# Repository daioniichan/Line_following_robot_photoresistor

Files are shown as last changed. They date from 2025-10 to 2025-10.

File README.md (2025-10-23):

# Line Following Robot - Algorithm Documentation

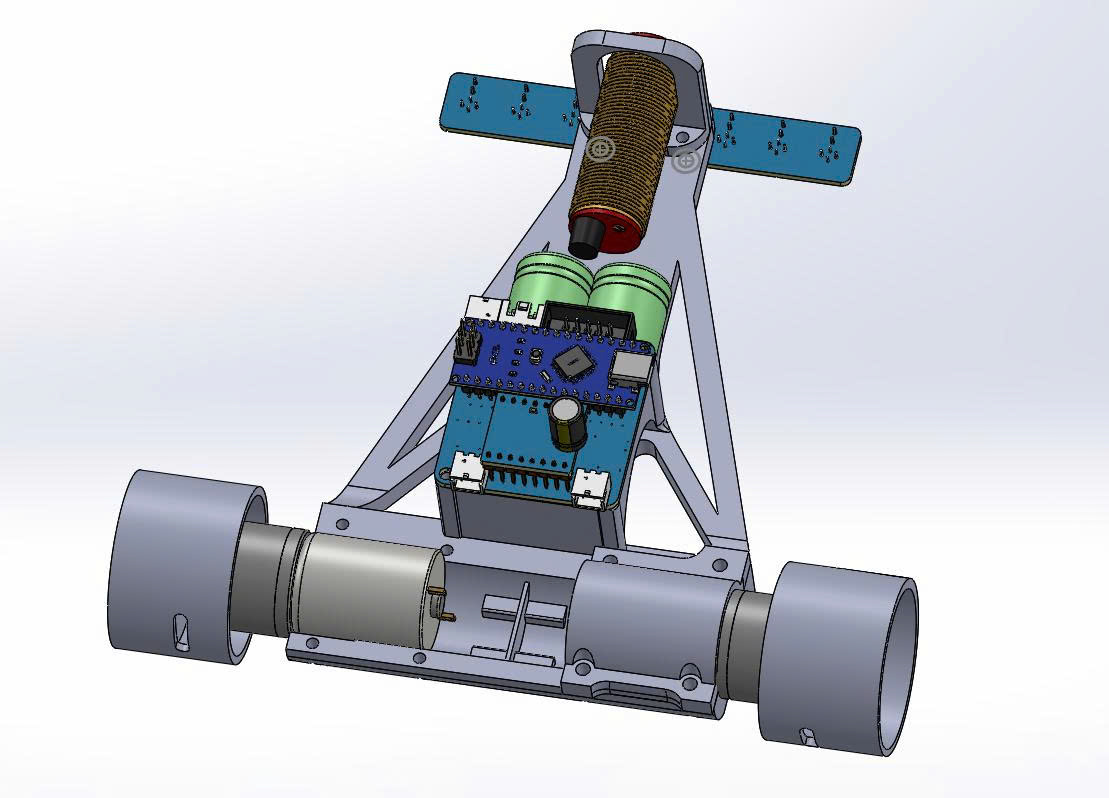
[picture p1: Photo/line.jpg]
anh1


## 📋 Tổng quan

Robot dò line sử dụng 8 cảm biến hồng ngoại với thuật toán PID để di chuyển theo đường line đen. Ngoài ra, robot còn có khả năng tránh vật cản sử dụng cảm biến NPN.

## 🔧 Cấu hình phần cứng

### Chân kết nối:
- **Cảm biến line**: A0-A7 (8 cảm biến analog)
- **Cảm biến vật cản**: Pin 2 (NPN_SENSOR_PIN)
- **Động cơ trái**: 
  - AIN1 (Pin 8), AIN2 (Pin 7)
  - PWMA (Pin 6)
- **Động cơ phải**:
  - BIN1 (Pin 4), BIN2 (Pin 3)
  - PWMB (Pin 5)
- **Nút điều khiển**:
  - SW1 (Pin 12), SW2 (Pin 9)
  - DIPSTW1 (Pin 10), DIPSTW2 (Pin 11)
- **Buzzer**: Pin 13

### Ánh xạ cảm biến:
```
sensorValue[7] ← A0 (trái ngoài cùng)
sensorValue[6] ← A2
sensorValue[5] ← A1
sensorValue[4] ← A4
sensorValue[3] ← A3
sensorValue[2] ← A6
sensorValue[1] ← A5
sensorValue[0] ← A7 (phải ngoài cùng)
```

## ⏱️ Timer Interrupt

### Cấu hình Timer 2:
- **Prescaler**: 1024
- **TCNT2**: 0xB2 (178)
- **Overflow**: 256 - 178 = 78 counts
- **Tần số ngắt**: (78 × 1024) / 16MHz ≈ **5ms**
- **Tần số đọc cảm biến**: **200 Hz**

Trong mỗi lần ngắt:
- Đọc giá trị 8 cảm biến
- Tính toán PID
- Tăng biến đếm `cnt`

## 🧮 Thuật toán PID

### 1. Calibration (Tự động chuẩn hóa)

Khi `isCalib = 1`, hệ thống tự động:
```cpp
if (black_value[i] == 0) black_value[i] = 1100;  // Khởi tạo
if (sensorValue[i] < black_value[i]) black_value[i] = sensorValue[i];  // Tìm min
if (sensorValue[i] > white_value[i]) white_value[i] = sensorValue[i];  // Tìm max
compare_value[i] = (black_value[i] + white_value[i]) / 2;  // Ngưỡng
```

### 2. Chuẩn hóa giá trị cảm biến

```cpp
sensorPID[j] = map(sensorValue[j], black_value[j], white_value[j], 0, 1000);
```
- Giá trị đen (line) → 0
- Giá trị trắng (nền) → 1000

### 3. Tạo byte sensor (binary representation)

```cpp
sensor = 0bXXXXXXXX  // 8 bit, mỗi bit đại diện cho 1 cảm biến
// Bit = 1 nếu cảm biến > compare_value (phát hiện trắng)
// Bit = 0 nếu cảm biến < compare_value (phát hiện đen/line)
```

**Ví dụ**:
- `0b00011000` = Line ở giữa (sensor 3, 4)
- `0b00000001` = Line ở phải ngoài cùng
- `0b10000000` = Line ở trái ngoài cùng
- `0b00011111` = Ngã tư (5 sensor phải phát hiện line)

### 4. Tính vị trí line (Weighted Average)

```cpp
avg = Σ(sensorPID[j] × j × 1000)  // j = 0..7
sum = Σ(sensorPID[j])
position = (avg / sum) - 3500
```

**Giải thích**:
- Vị trí trung tâm lý tưởng: (0+1+2+3+4+5+6+7)/8 × 1000 = 3500
- `position < 0`: Line lệch về phải
- `position > 0`: Line lệch về trái
- `position = 0`: Line ở chính giữa

### 5. Điều khiển PID

```cpp
kp = 2.0      // Hệ số tỷ lệ
kd = 15       // Hệ số vi phân

iP = kp × position                    // Phần tỷ lệ
iD = kd × (lastPos - position)        // Phần vi phân
iRet = iP - iD                        // Tổng điều khiển

if (iRet < -4000) iRet = 0;          // Giới hạn quá âm
servoPwm = iRet / 25                  // Chia tỷ lệ
```

**Ý nghĩa**:
- **P (Proportional)**: Điều chỉnh mạnh khi lệch nhiều
- **D (Derivative)**: Giảm dao động, làm mượt chuyển động
- `servoPwm > 0`: Rẽ trái
- `servoPwm < 0`: Rẽ phải

### 6. Áp dụng vào động cơ

```cpp
speedLeft = baseSpeed - servoPwm
speedRight = baseSpeed + servoPwm
```

## 🎮 Chế độ hoạt động

### Khởi động (start = 0)

#### Chế độ 1: DIPSTW1=HIGH, DIPSTW2=HIGH
- **SW1**: Bắt đầu từ case 10
- **SW2**: Bắt đầu từ case 11

#### Chế độ 2: DIPSTW1=LOW, DIPSTW2=LOW
- **SW1**: Bắt đầu từ case 14 (test ngã 4)
- **SW2**: Bắt đầu từ case 341 (test tránh vật cản)

## 🗺️ Sơ đồ thuật toán chính

### 📍 Luồng Line Following (Case 10-19)

```
Case 10: Chờ 2.25s
    ↓
Case 11: Chạy line (150) → Phát hiện ngã tư đầu tiên (5 sensor)
    ↓
Case 13: Tiến + rẽ nhẹ phải (100ms)
    ↓
Case 214-216: Quét phải tìm line mới
    ↓
Case 14: Chạy line → Phát hiện ngã 4
    ↓
Case 15-151: Quét trái qua ngã 4
    ↓
Case 141: Chạy line → Kiểm tra vật cản
    ↓ (không có vật cản)
Case 142-143: Điều chỉnh vị trí + quét phải
    ↓
Case 16: Chạy line → Phát hiện mất line (sensor = 0x00)
    ↓
Case 17-18: Quay phải tìm line
    ↓
Case 19: Chạy line
    ↓ (nếu sensor = 0xf0 → Case 100: DỪNG)
    ↓ (nếu timeout 500ms)
Case 34-351: Xử lý ngã 4 thứ 2
    ↓
Case 341: Vào chế độ tránh vật cản
```

### 🚧 Luồng Tránh Vật Cản (Case 341-352)

```
Case 341: Chạy line + kiểm tra NPN sensor
    ↓ (phát hiện vật cản)
Case 342: Lùi xe (400ms)
    ↓
Case 343: Quay phải tại chỗ (250ms)
    ↓
Case 344: Tiến thẳng (1750ms) - đi vòng qua vật cản
    ↓
Case 345: Quay trái tại chỗ (600ms)
    ↓
Case 348: Tiến đến khi gặp line
    ↓
Case 349: Tiến thêm (350ms)
    ↓
Case 350: Quay phải tìm line chính giữa
    ↓
Case 352: Chạy line bình thường
```

**Hình dạng quỹ đạo tránh vật cản**:
```
    ┌─────────┐
    │ Vật cản │
    └─────────┘
         ▲
    3    │    1
    ┌────┴────┐
    │         │
  4 └─────────┘ 2
       Line
```
1. Phát hiện → Lùi
2. Quay phải
3. Tiến dài (vượt vật cản)
4. Quay trái (về song song với line)
5. Tìm lại line

## 📊 Bảng mã sensor quan trọng

| Mã Binary | Hex | Ý nghĩa |
|---|-----|---|
| `0b00011000` | 0x18 | Line ở giữa (sensor 3,4) |
| `0b00111100` | 0x3C | Line ở giữa rộng (sensor 2,3,4,5) |
| `0b00001111` | 0x0F | Ngã tư phải (4 sensor phải) |
| `0b00011111` | 0x1F | Ngã tư phải đầy đủ (5 sensor phải) |
| `0b11110000` | 0xF0 | Ngã tư trái (4 sensor trái) |
| `0b11111000` | 0xF8 | Ngã tư trái đầy đủ (5 sensor trái) |
| `0b11111100` | 0xFC | 6 sensor trái |
| `0b11000011` | 0xC3 | Line ở 2 đầu |
| `0b00000000` | 0x00 | Mất line hoàn toàn |

## ⚙️ Tham số điều chỉnh

### PID Parameters:
```cpp
kp = 2.0    // Tăng → phản ứng mạnh hơn, dễ dao động
kd = 15     // Tăng → mượt hơn, giảm overshoot
divider = 25 // servoPwm = iRet / 25 - Tăng → chuyển hướng nhẹ hơn
```

### Tốc độ:
```cpp
Case 11, 141: 150-180  // Tốc độ chạy line thường
Case 16: 100           // Tốc độ chậm (gần điểm đặc biệt)
Case 341: 100          // Tốc độ khi kiểm tra vật cản
```

### Thời gian (cnt × 5ms):
```cpp
cnt = 80  → 400ms
cnt = 100 → 500ms
cnt = 350 → 1750ms
```

## 🛠️ Hàm chính

### `read_sensor()`
- Đọc 8 cảm biến analog
- Chuẩn hóa giá trị (0-1000)
- Tạo byte sensor
- Tính PID
- Cập nhật servoPwm

### `speed_run(left, right)`
- Điều khiển 2 động cơ
- Giới hạn tốc độ (-255 đến 255)
- Âm = lùi, Dương = tiến

### `handleAndSpeed(angle, speed)`
- `speedLeft = speed - angle`
- `speedRight = speed + angle`
- Điều khiển xe rẽ trong khi di chuyển

### `runforwardline(speed)`
- Wrapper cho `handleAndSpeed(servoPwm, speed)`
- Chạy line với tốc độ cho trước

### `sensorMask(mask)` & `sensorE()`
- Kiểm tra trạng thái sensor với bit mask
- `sensorE()`: Trả về toàn bộ byte sensor

## 🔍 Debug

Uncomment để debug:
```cpp
// Trong loop():
Serial.print(sensor, BIN);
Serial.print(" | Servo PWM: ");
Serial.println(servoPwm);

// Trong update_sensor():
Serial.println(sensor, BIN);
```

## 📝 Lưu ý

1. **Calibration tự động**: Để xe trên line trắng, bật calibration mode để tự học giá trị min/max
2. **Điều kiện cắt PID**: `if (iRet < -4000) iRet = 0` - chỉ cắt giá trị âm quá lớn
3. **Timer interrupt**: Không dùng `delay()` trong ISR
4. **Biến volatile**: `cnt`, `servoPwm`, `sensor`, `lastPos` - dùng chung giữa ISR và main

## 🎯 Kịch bản sử dụng

### Test cơ bản:
1. Set DIPSTW = HIGH-HIGH
2. Nhấn SW1 → Chạy từ đầu (case 10)
3. Nhấn SW2 → Chạy từ ngã tư đầu (case 11)

### Test ngã 4:
1. Set DIPSTW = LOW-LOW
2. Nhấn SW1 → Test ngã 4 (case 14)

### Test tránh vật cản:
1. Set DIPSTW = LOW-LOW
2. Nhấn SW2 → Test obstacle avoidance (case 341)

---

**Tác giả**: Line Following Robot Project  
**Ngày cập nhật**: 23/10/2025  
**Phiên bản**: 2.0

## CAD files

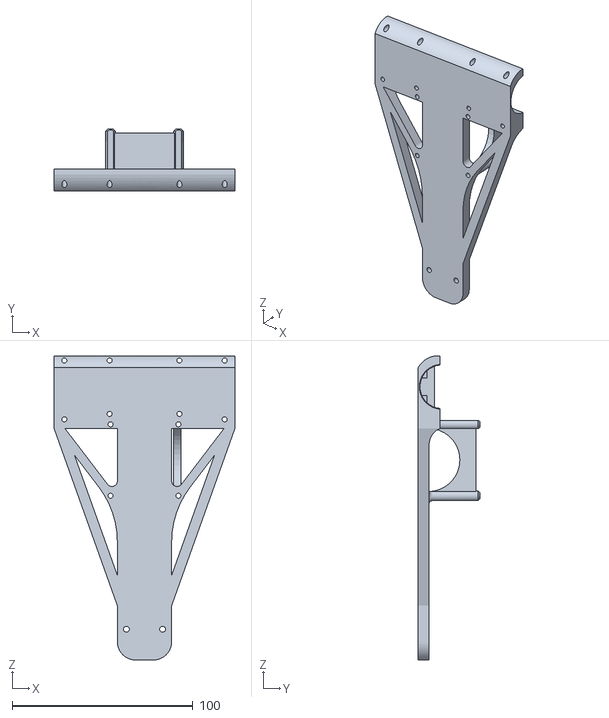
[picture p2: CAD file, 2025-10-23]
3D Model/ditxe.STL
100.0 x 34.0 x 168.0

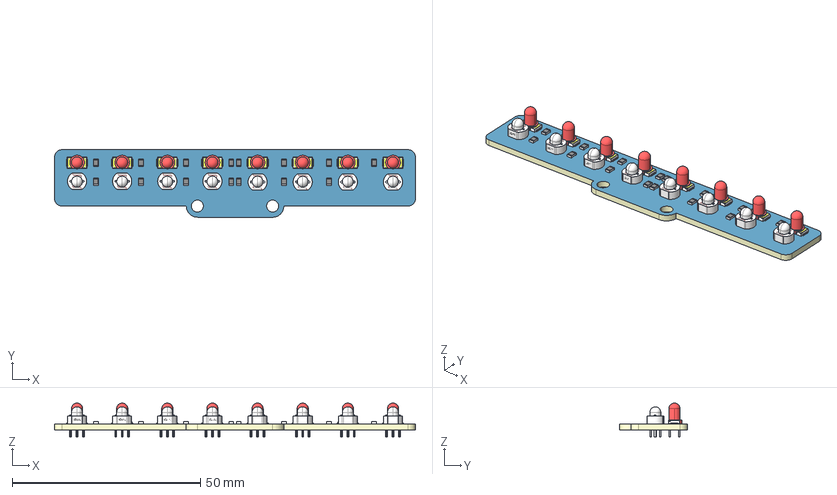
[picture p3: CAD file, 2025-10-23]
3D Model/3D_PCB_analogsensor_2025-10-22.step
96.0 x 18.0 x 9.00 mm
Board~aGic
TopCopper~aGic
BottomCopper~aGic
TopFpcStiffener~aGic
BottomFpcStiffener~aGic
R0805~R0805_L2.0-W1.3-H0.6~aGic x 15
LED-TH_BD3.2-P2.54-FD~LED-TH_BD3.2-H4.5-P2.54~aGic x 8
RES-TH_L5.1-W4.3-P3.40-D0.5~RES-TH_L5.1-W4.3-P3.40-D0.5~aGic x 8
LED-TH_BD3.0-P2.54-FD~LED-TH-3mm_R~aGic x 8
LED-SMD_3P-L5.7-W3.0-RD-CUSTOM~LED-SMD_3P-L5.7-W3.0-H0.8~aGic x 8

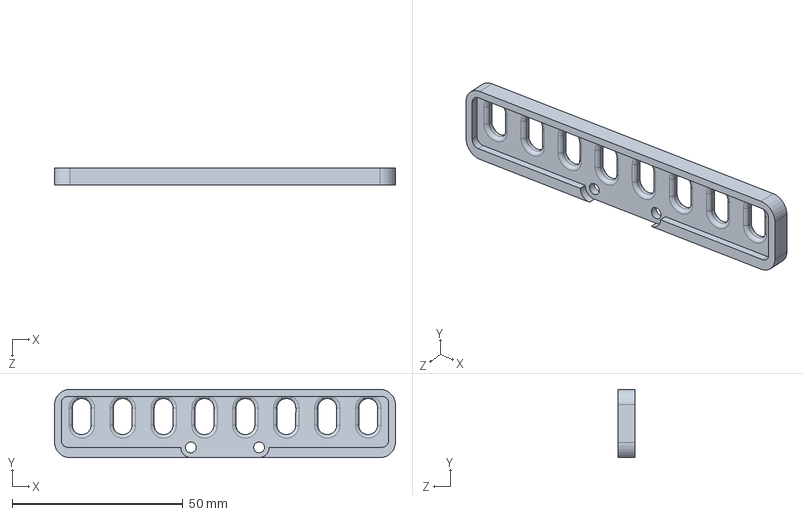
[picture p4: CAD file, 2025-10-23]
3D Model/3D_PCB_analogsensor_2025-10-22.step.SLDPRT
100.0 x 20.0 x 5.00 mm

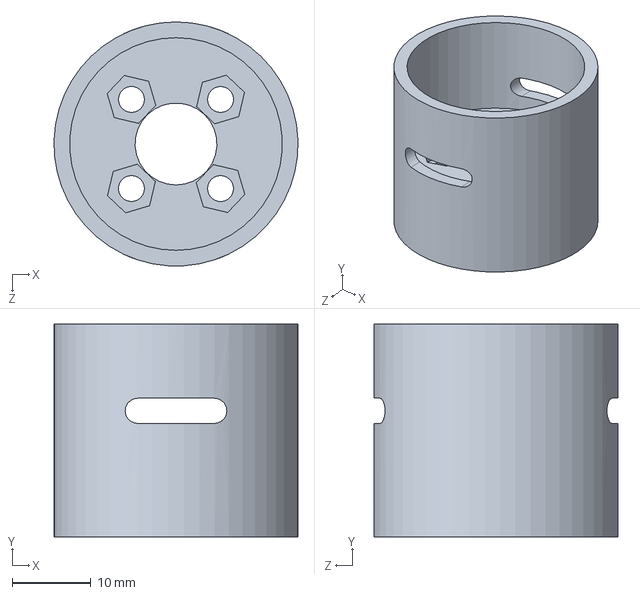
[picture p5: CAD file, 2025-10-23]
3D Model/BANHXEGA25.SLDPRT
31.0 x 27.0 x 31.0 mm

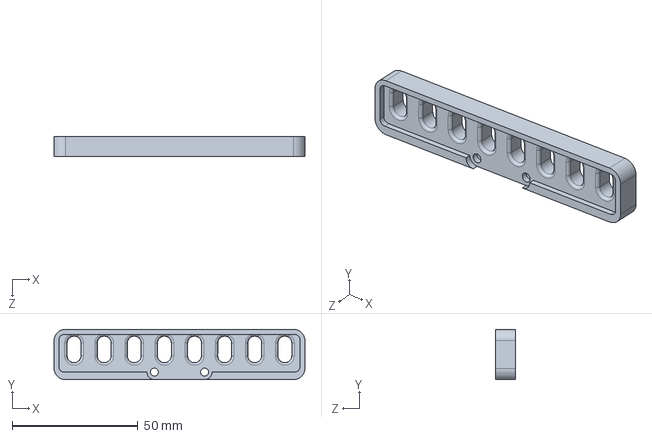
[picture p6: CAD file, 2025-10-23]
3D Model/3D_PCB_analogsensor_2025-10-22 v2 .step.SLDPRT
100.0 x 20.0 x 8.00 mm

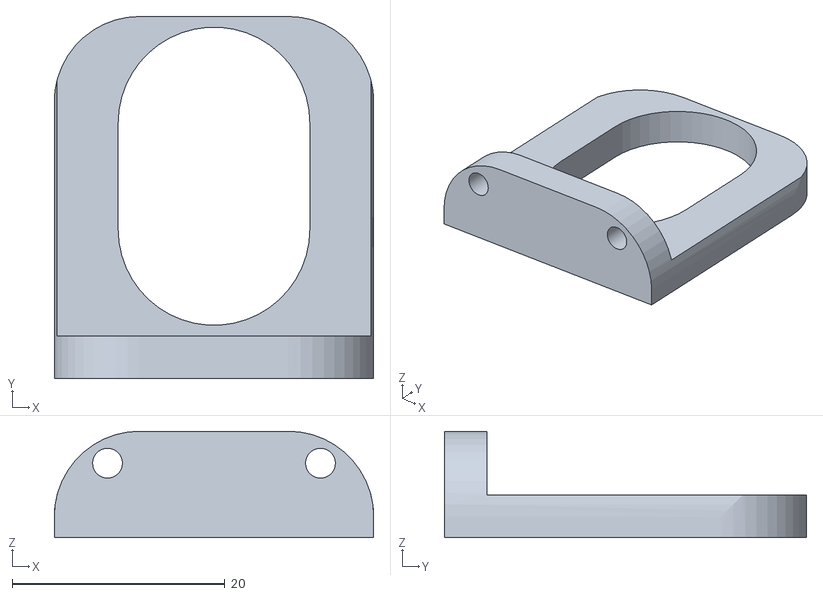
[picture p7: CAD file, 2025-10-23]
3D Model/deSS.STL
30.0 x 34.0 x 10.0

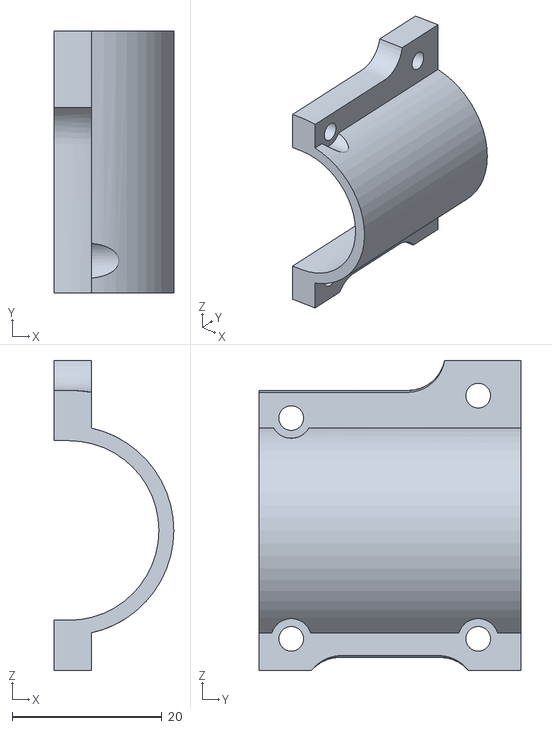
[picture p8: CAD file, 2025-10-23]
3D Model/padbatga25.STL
16.0 x 35.0 x 41.4

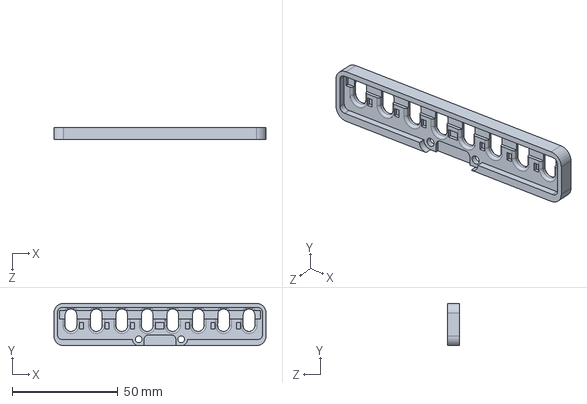
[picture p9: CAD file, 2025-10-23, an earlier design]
3D Model/3D_PCB_analogsensor_2025-10-22 v1 .step.SLDPRT
100.0 x 20.0 x 5.50 mm

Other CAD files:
3D Model/3D_PCB_analogsensor_2025-10-22 v1 .step.STL
3D Model/3D_PCB_analogsensor_2025-10-22.step.STL
3D Model/BANHXEGA25.STL

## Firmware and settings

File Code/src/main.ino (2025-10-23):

#include <Arduino.h>

unsigned char start = 0;
int pattern = 0;
// uint16_t sensorValue[8];
// uint16_t sensorPID[8];
// uint16_t black_value[8] = {964,962,934,934,977,955,952,967};
// uint16_t white_value[8] = {762,756,737,720,794,759,808,797};
// uint16_t compare_value[8];
unsigned int sensorValue[8] = {0, 0, 0, 0, 0, 0, 0, 0};
unsigned int sensorPID[8] = {0, 0, 0, 0, 0, 0, 0, 0};
unsigned int black_value[8] = {0, 0, 0, 0, 0, 0, 0, 0};
unsigned int white_value[8] = {0, 0, 0, 0, 0, 0, 0, 0};
unsigned int compare_value[8] = {0, 0, 0, 0, 0, 0, 0, 0};
float kp;
int kd;
volatile int lastPos;
volatile unsigned char isCalib = 0;
volatile int servoPwm;
volatile unsigned char sensor;
volatile int cnt = 0; // Đổi thành volatile để an toàn với ISR
int RememberLine = 0; // Biến mới để nhớ hướng line mất
int LineCount = 0;    // Biến đếm số line

#define BUZZER_PIN 13
#define SW1_PIN 12
#define SW2_PIN 9
#define DIPSTW1_PIN 10
#define DIPSTW2_PIN 11
#define NPN_SENSOR_PIN 2
#define AIN1_PIN 8
#define AIN2_PIN 7
#define PWMA_PIN 6
#define PWMB_PIN 5
#define BIN1_PIN 4
#define BIN2_PIN 3
void test1();
void test2();
void speed_run(int speedDC_left, int speedDC_right);
void handleAndSpeed(int angle, int speed1);
void read_sensor_v1();
void read_sensor();
unsigned char sensorMask(unsigned char mask);
unsigned char sensorE();
void runforwardline(int tocdo);
void update_sensor();
void beep(int duration);
void analog_raw();

void timer_init()
{
  // Timer/Counter 2 initialization
  ASSR = (0 << EXCLK) | (0 << AS2);
  TCCR2A = (0 << COM2A1) | (0 << COM2A0) | (0 << COM2B1) | (0 << COM2B0) | (0 << WGM21) | (0 << WGM20);
  TCCR2B = (0 << WGM22) | (1 << CS22) | (1 << CS21) | (1 << CS20);
  TCNT2 = 0xB2;
  OCR2A = 0x00;
  OCR2B = 0x00;
  // Timer/Counter 2 Interrupt(s) initialization
  TIMSK2 = (0 << OCIE2B) | (0 << OCIE2A) | (1 << TOIE2);
}
ISR(TIMER2_OVF_vect)
{
  TCNT2 = 0xB2;
  read_sensor();
  cnt++;
}

void setup()
{
  // for (int i = 0; i < 8; i++)
  // {
  //   compare_value[i] = (black_value[i] + white_value[i]) / 2;
  // }
  Serial.begin(9600);
  pinMode(BUZZER_PIN, OUTPUT);
  digitalWrite(BUZZER_PIN, HIGH);     // Turn the buzzer off
  pinMode(SW1_PIN, INPUT_PULLUP);     // left switch
  pinMode(SW2_PIN, INPUT_PULLUP);     // right switch
  pinMode(DIPSTW1_PIN, INPUT_PULLUP); // upper switch
  pinMode(DIPSTW2_PIN, INPUT_PULLUP); // lower switch
  pinMode(NPN_SENSOR_PIN, INPUT);
  pinMode(AIN1_PIN, OUTPUT);
  pinMode(AIN2_PIN, OUTPUT);
  pinMode(PWMA_PIN, OUTPUT);
  pinMode(PWMB_PIN, OUTPUT);
  pinMode(BIN1_PIN, OUTPUT);
  pinMode(BIN2_PIN, OUTPUT);
  timer_init();
  isCalib = 1;
  pattern = 0;
  start = 0;
}
void loop1()
{
  speed_run(100, 0);
}
void loop()
{
  // while (start == 0)
  // {
  //   update_sensor();
  //   if (digitalRead(DIPSTW1_PIN) == LOW && digitalRead(DIPSTW2_PIN) == LOW){
  //     if (digitalRead(SW1_PIN) == LOW)
  //     {
  //       isCalib = 0;
  //       start = 1;
  //       pattern = 9;
  //       cnt = 0;
  //     }
  //   }
  //   else if (digitalRead(DIPSTW1_PIN) == LOW && digitalRead(DIPSTW2_PIN) == HIGH){
  //     isCalib = 0;
  //     Serial.print(sensor, BIN);
  //     for(int i=0;i<8;i++){
  //       Serial.print(" | S");
  //       Serial.print(i);
  //       Serial.print(": ");
  //       Serial.print(sensorPID[i]);
  //     }
  //     Serial.print(" | Servo PWM: ");
  //     Serial.println(servoPwm);
  //   }
  //   else if (digitalRead(DIPSTW1_PIN) == HIGH && digitalRead(DIPSTW2_PIN) == LOW)
  //   {
  //     isCalib = 1;
  //     update_sensor();
  //   }
  //   else
  //   {
  //     if (digitalRead(SW1_PIN) == LOW)
  //     {
  //       isCalib = 0;
  //       start = 1;
  //       pattern = 10;
  //       cnt = 0;
  //     }
  //     if (digitalRead(SW2_PIN) == LOW)
  //     {
  //       isCalib = 0;
  //       start = 1;
  //       pattern = 11;
  //       cnt = 0;
  //     }
  //   }
  // }
  while (start == 0)
  {
    update_sensor();
    if(digitalRead(DIPSTW1_PIN)== HIGH && digitalRead(DIPSTW2_PIN)== HIGH)
     {
    if (digitalRead(SW1_PIN) == LOW)
    {
      isCalib = 0;
      start = 1;
      pattern = 10;
      cnt = 0;
    }
    if (digitalRead(SW2_PIN) == LOW)
    {
      isCalib = 0;
      start = 1;
      pattern = 11;
      cnt = 0;
    }
  }
  else if(digitalRead(DIPSTW1_PIN)== LOW && digitalRead(DIPSTW2_PIN)== LOW)
     {
    if (digitalRead(SW1_PIN) == LOW)
    {
      isCalib = 0;
      start = 1;
      pattern = 14;
      cnt = 0;
    }
    if (digitalRead(SW2_PIN) == LOW)
    {
      isCalib = 0;
      start = 1;
      pattern = 341;
      cnt = 0;
    }
  }
}
  // setservotime(nang, ServoPWMChannel3);
  // speed_run(0  ,0);
  switch (pattern)
  {
  case 9:
    runforwardline(0);
    break;
  case 10:
    if (cnt >= 450)
    { // Scale từ 90 cho 5ms (giữ ~450ms)
      pattern = 11;
      cnt = 0; // Reset cnt
      break;
    }
    // if (sensorMask(0x0e) == 0x0e)
    // {
    //   int oldCnt = cnt;
    //   while (cnt - oldCnt < 60)
    //   {                    // Giữ trong 100 ticks (khoảng 0.5 giây)
    //     speed_run(100, 100); // di chuyển thẳng
    //   }
    // }
    runforwardline(150);
    break;
  case 11:
    runforwardline(150);
    if (sensorMask(0x1f) == 0x1f || sensorMask(0x0f) == 0x0f)
    {
      speed_run(0, 0);
      beep(50);
      cnt = 0;
      pattern = 13;
      break;
    }
    break;
  case 13:
    speed_run(100, 25);
    if (cnt >= 80)
    {
      cnt = 0;
      pattern = 214;
      break;
    }
    break;
  case 214:
    speed_run(100, -50);
    if (sensorMask(0x3c) != 0x00)
    {
      speed_run(0, 0);
      beep(50);
      cnt = 0;
      pattern = 215;
      break;
    }
    break;
  case 215:
    speed_run(100, -50);
    if (sensorMask(0xfc) != 0x00)
    {
      speed_run(0, 0);
      beep(50);
      cnt = 0;
      pattern = 216;
      break;
    }
    break;
  case 216: // hoan thanh quet phai
    runforwardline(180);
    if (cnt >= 100)
    {
      cnt = 0;
      pattern = 14;
      break;
    }
    break;
  case 14:
    runforwardline(180);
    if (sensorMask(0x1f) == 0x1f || sensorMask(0x0f) == 0x0f || sensorMask(0xf0) == 0xf0 || sensorMask(0xf8) == 0xf8)
    {
      speed_run(0, 0);
      beep(50);
      cnt = 0;
      pattern = 15;
      break;
    }
    break;
  case 15: // quet trai nga 4
    speed_run(25, 100);
    if (cnt >= 80)
    {
      cnt = 0;
      pattern = 151;
      break;
    }
    break;
  case 151:
    speed_run(-50, 100);
    if (sensorMask(0x3c) != 0x00)
    {
      speed_run(0, 0);
      beep(50);
      cnt = 0;
      pattern = 141;
      break;
    }
    break;
  case 141: // hoan thanh quet

    runforwardline(180);
    if (sensorMask(0x1f) == 0x1f || sensorMask(0x0f) == 0x0f || sensorMask(0x07) == 0x07)
    {
      cnt = 0;
      pattern = 142;
      break;
    }
    if (digitalRead(NPN_SENSOR_PIN) == LOW) // object detected
    {
      speed_run(0, 0);
      beep(50);
      cnt = 0;
      pattern = 100; // stop
      break;
    }
    break;
  case 142:
    speed_run(150, 25);
    if (cnt >= 80)
    {
      cnt = 0;
      pattern = 143;
      break;
    }
    break;
  case 143:
    speed_run(150, -75);
    if (sensorMask(0xc3) != 0x00)
    {
      cnt = 0;
      pattern = 16;
      break;
    }
    break;
  case 16:

    runforwardline(100);
    if (sensorE() == 0x00)
    {
      speed_run(0, 0);
      beep(50);
      cnt = 0;
      pattern = 17;
      break;
    }
    break;
  case 17:
    speed_run(100, -50);
    if (cnt >= 50)
    {
      cnt = 0;
      pattern = 18;
      break;
    }
    break;
  case 18:
    speed_run(100, -100);
    if (sensorMask(0x3c) != 0x00)
    {
      speed_run(0, 0);
      beep(50);
      cnt = 0;
      pattern = 19;
      break;
    }
    break;
  case 19:
    runforwardline(150);
    if (sensorE() == 0xf0)
    {
      speed_run(0, 0);
      beep(50);
      cnt = 0;
      pattern = 100;
      break;
    }
    if(cnt >= 100){
      cnt = 0;
      pattern = 34;
      break;
    }
    break;
  case 20:
    speed_run(50, 50);
    if (cnt >= 80)
    {
      cnt = 0;
      pattern = 21;
      break;
    }
    break;
  case 21: // check point so 4
    speed_run(-150, 75);
    if (sensorMask(0x3c) != 0x00)
    {
      speed_run(0, 0);
      beep(50);
      cnt = 0;
      pattern = 34;
      break;
    }
    break;
  case 34:
    runforwardline(180);
    if (sensorMask(0x1f) == 0x1f || sensorMask(0x0f) == 0x0f || sensorMask(0xf0) == 0xf0 || sensorMask(0xf8) == 0xf8)
    {
      speed_run(0, 0);
      beep(50);
      cnt = 0;
      pattern = 35;
      break;
    }
    break;
  case 35: // quet trai nga 4
    speed_run(25, 100);
    if (cnt >= 80)
    {
      cnt = 0;
      pattern = 351;
      break;
    }
    break;
  case 351:
    speed_run(-50, 100);
    if (sensorMask(0x3c) != 0x00)
    {
      speed_run(0, 0);
      beep(50);
      cnt = 0;
      pattern = 341;
      break;
    }
    break;
  case 341: // hoan thanh quet
    runforwardline(100);
    if (digitalRead(NPN_SENSOR_PIN) == LOW) // object detected
    {
      speed_run(0, 0);
      beep(50);
      cnt = 0;
      pattern = 342; // stop
      break;
    }
    break;
  case 342:
    speed_run(-70,-70);
    if (cnt >= 80)
    {
      cnt = 0;
      pattern = 343;
      break;
    }
    break;
  case 343:
    speed_run(70, -70);
    if (cnt >= 50)
    {
      cnt = 0;
      pattern = 344;
      break;
    }
    break;
  case 344:
    speed_run(70,70);
    if (cnt >= 200)
    {
      cnt = 0;
      pattern = 345;
      break;
    }
    break;
  case 345:
    speed_run(-70,70);
    if(cnt >=70){
      cnt =0;
      pattern =348;
      break;
    }
    break;
  case 348:
    speed_run(70,70);
    if(sensorMask(0x3c) != 0x00){
      cnt =0;
      pattern =100;
      break;
    }
    break;
  case 349:
    speed_run(50,50);
    if(cnt >=70){
      cnt =0;
      pattern =348;
      break;
    }
    break;
  case 350:
    speed_run(70,-70);
    if(sensorMask(0x18) == 0x18){
      cnt =0;
      pattern =352;
      break;
    }
    break;
  case 352:
    runforwardline(100);
    break;
  case 100:
    speed_run(0, 0);
    break;
  default:
    break;
}
}
void test1()
{
  // Serial.println("A"); // Read NPN sensor value
  if (digitalRead(SW1_PIN) == LOW)
  {
    speed_run(20, 20); // Move forward
  }
  else if (digitalRead(SW2_PIN) == LOW)
  {
    speed_run(-20, -20); // Move backward
  }
  else
  {
    speed_run(0, 0); // Stop
  }
}
void test2()
{
  if (digitalRead(SW1_PIN) == LOW)
  {
    speed_run(-70, 0); // Turn right
  }
  else if (digitalRead(SW2_PIN) == LOW)
  {
    speed_run(0, -70); // Turn left
  }
  else
  {
    speed_run(0, 0); // Stop
  }
}
void speed_run(int speedDC_left, int speedDC_right) // hàm truyền vào tốc độ động cơ trái + phải
{
  if (speedDC_left > 255)
  {
    speedDC_left = 255;
  }
  else if (speedDC_left < -255)
  {
    speedDC_left = -255;
  }
  if (speedDC_right > 255)
  {
    speedDC_right = 255;
  }
  else if (speedDC_right < -255)
  {
    speedDC_right = -255;
  }
  // Debugging: Print input values
  // Serial.print("Speed Left: ");
  // Serial.print(speedDC_left);
  // Serial.print(", Speed Right: ");
  // Serial.println(speedDC_right);

  if (speedDC_left < 0)
  {
    analogWrite(PWMA_PIN, -speedDC_left);
    digitalWrite(AIN1_PIN, HIGH);
    digitalWrite(AIN2_PIN, LOW);
  }
  else if (speedDC_left > 0)
  {
    analogWrite(PWMA_PIN, speedDC_left);
    digitalWrite(AIN1_PIN, LOW);
    digitalWrite(AIN2_PIN, HIGH);
  }
  else
  {
    analogWrite(PWMA_PIN, 0);
    digitalWrite(AIN1_PIN, LOW);
    digitalWrite(AIN2_PIN, LOW);
  }
  if (speedDC_right > 0)
  {
    analogWrite(PWMB_PIN, speedDC_right);
    digitalWrite(BIN1_PIN, HIGH);
    digitalWrite(BIN2_PIN, LOW);
  }
  else if (speedDC_right < 0)
  {
    analogWrite(PWMB_PIN, -speedDC_right);
    digitalWrite(BIN1_PIN, LOW);
    digitalWrite(BIN2_PIN, HIGH);
  }
  else
  {
    analogWrite(PWMB_PIN, 0);
    digitalWrite(BIN1_PIN, LOW);
    digitalWrite(BIN2_PIN, LOW);
  }

  // Debugging: Confirm PWM values written
  // Serial.println("PWM values written.");
}
void handleAndSpeed(int angle, int speed1)
{
  int speedLeft;
  int speedRight;
  // if ((speed1 + angle) > 255)
  // {
  //   speed1 = 255 - angle;
  // }
  // if ((speed1 - angle) > 255)
  // {
  //   speed1 = 255 + angle;
  // }
  speedLeft = speed1 - angle;
  speedRight = speed1 + angle;
  speed_run(speedLeft, speedRight);
}
void read_sensor()
{
  unsigned char temp = 0;
  unsigned int sum = 0;
  unsigned long avg = 0;
  int i, iP, iD;
  int iRet;
  sensorValue[7] = analogRead(A0);
  sensorValue[6] = analogRead(A2);
  sensorValue[5] = analogRead(A1);
  sensorValue[4] = analogRead(A4);
  sensorValue[3] = analogRead(A3);
  sensorValue[2] = analogRead(A6);
  sensorValue[1] = analogRead(A5);
  sensorValue[0] = analogRead(A7);
  for (int j = 0; j < 8; j++)
  {
    if (isCalib == 0)
    {
      if (sensorValue[j] < black_value[j])
        sensorValue[j] = black_value[j];
      if (sensorValue[j] > white_value[j])
        sensorValue[j] = white_value[j];
      sensorPID[j] = map(sensorValue[j], black_value[j], white_value[j], 0, 1000);
    }
    temp = temp << 1;
    if (sensorValue[j] > compare_value[j])
    {
      temp |= 0x01; // nếu cảm biến j có giá trị lớn hơn giá trị tham chiếu thì gán bit j của temp = 1
      // temp = temp |
    }
    else
    {
      temp &= 0xfe;
    }
    sensor = temp;
  }
  for (int j = 0; j < 8; j++)
  {
    avg += (long)(sensorPID[j]) * ((j) * 1000);
    sum += sensorPID[j];
  }
  i = (int)((avg / sum) - 3500);
  kp = 2;  // 1.2 //2
  kd = 15; // 12 //15
  iP = kp * i;
  iD = kd * (lastPos - i);
  iRet = (iP - iD);
  if ((iRet < -4000))
  {
    iRet = 0;
  }
  servoPwm = iRet / 25; // 12 //25
  lastPos = i;
}
void read_sensor_v1() // hàm đọc cảm biến
{
  unsigned char temp = 0;
  unsigned int sum = 0;
  unsigned long avg = 0;
  int i, iP, iD;
  int iRet;
  sensorValue[0] = analogRead(A0);
  sensorValue[1] = analogRead(A2);
  sensorValue[2] = analogRead(A1);
  sensorValue[3] = analogRead(A4);
  sensorValue[4] = analogRead(A3);
  sensorValue[5] = analogRead(A6);
  sensorValue[6] = analogRead(A5);
  sensorValue[7] = analogRead(A7);
  for (int j = 0; j < 8; j++)
  {
    sensorPID[j] = map(sensorValue[j], black_value[j], white_value[j], 0, 1000);
    sensorPID[j] = constrain(sensorPID[j], 0, 1000);
    temp = temp << 1;
    if (sensorValue[j] > compare_value[j])
    {
      temp |= 0x01; // nếu cảm biến j có giá trị lớn hơn giá trị tham chiếu thì gán bit j của temp = 1
      // temp = temp |
    }
    else
    {
      temp &= 0xfe;
    }
    sensor = temp;
  }
  for (int j = 0; j < 8; j++)
  {
    avg += (long)(sensorPID[j]) * ((j) * 1000);
    sum += sensorPID[j];
  }
  i = (int)((avg / sum) - 3500);
  kp = 1;  // 1.2
  kd = 10; // 12
  iP = kp * i;
  iD = kd * (lastPos - i);
  iRet = (iP - iD);
  if ((iRet < -4000))
  {
    iRet = 0;
  }
  servoPwm = iRet / 20; // 12
  lastPos = i;
}
unsigned char sensorMask(unsigned char mask)
{
  return sensor & mask;
}
unsigned char sensorE()
{
  return sensor;
}
void runforwardline(int tocdo)
{
  handleAndSpeed(servoPwm, tocdo);
}
void update_sensor()
{
  // sensorValue[0] =  analogRead(A0);
  // sensorValue[1] =  analogRead(A2);
  // sensorValue[2] =  analogRead(A1);
  // sensorValue[3] =  analogRead(A4);
  // sensorValue[4] =  analogRead(A3);
  // sensorValue[5] =  analogRead(A6);
  // sensorValue[6] =  analogRead(A5);
  // sensorValue[7] =  analogRead(A7);
  // for (int i = 0; i < 8; i++)
  // {
  //   Serial.print(sensorValue[i]);
  //   if (i < 7)
  //   {
  //     Serial.print(",");
  //   }
  // }
  // Serial.println();
  Serial.println(sensor, BIN);
  for (int i = 0; i < 8; i++)
  {
    // Serial.print(sensorValue[i]);
    // Serial.print("  ");
    if (black_value[i] == 0)
      black_value[i] = 1100;
    if (sensorValue[i] < black_value[i])
      black_value[i] = sensorValue[i];
    if (sensorValue[i] > white_value[i])
      white_value[i] = sensorValue[i];
    compare_value[i] = (black_value[i] + white_value[i]) / 2;
  }
  // Serial.println();
}
void analog_raw()
{
  Serial.print("Sensor Raw Values: ");
  for (int i = 0; i < 8; i++)
  {
    Serial.print(sensorValue[i]);
    if (i < 7)
    {
      Serial.print(", ");
    }
  }
  Serial.println();
}
void beep(int duration)
{
  digitalWrite(BUZZER_PIN, LOW); // Turn the buzzer on
  delay(duration);
  digitalWrite(BUZZER_PIN, HIGH); // Turn the buzzer off
}
